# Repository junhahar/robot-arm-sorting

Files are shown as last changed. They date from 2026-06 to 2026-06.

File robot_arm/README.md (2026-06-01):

# Robot Arm Sorting

삼보모터스 실무 프로젝트. 5축 로봇암으로 볼트/너트를 인식해 자동 분류한다.

## 프로젝트 개요

전체 동작은 **마스터 궤적 재생 + Checkpoint AI 보정 하이브리드** 방식이다. 사람이 시연한 큰 동선을 그대로 재생하되, 정밀이 필요한 핵심 구간에서만 카메라·ToF 센서로 실시간 보정한다.

1. **하드웨어 구축** — 5관절축 로봇암 프레임 설계·제작, 부품 통합 및 배선 정리
2. **MPU 웨이포인트 티칭** — 사람 팔에 부착한 MPU로 동작을 녹화해 마스터 궤적(CSV) 생성
3. **볼트/너트 딥러닝 분류** — 그리퍼에 부착된 글로벌 셔터 카메라 + YOLO(Hailo 8L)로 실시간 판별
4. **실시간 위치 보정** — 작업 도중 물체 위치가 바뀌면 Checkpoint(SCAN/PRE_GRASP/GRASP/PLACE)에서 카메라·ToF·ArUco로 경로 보정

```
[티칭]  Nano#2(USB) + TCA9548A + MPU6050×3 → 노트북 → 웨이포인트 저장 → master_trajectory.csv
[자동]  RPi5가 CSV 재생 → checkpoint에서 YOLO/ToF/ArUco 보정 → 반복
```

---

## 하드웨어 구성

### 컴퓨팅 / 제어

| 장치 | 역할 | 비고 |
|---|---|---|
| 라즈베리파이5 + Hailo 8L | AI 추론(분류), 메인 제어, 궤적 재생 | CAN 마스터 |
| 노트북 | 티칭 데이터 수집, 모델 학습, 디버깅 | CAN 비참여 |
| STM32F103RB (Nucleo-F103RB) | 서보 6개 구동, 그리퍼 PWM | CAN 노드 |
| Arduino Nano #1 | VL53L0X(ToF) 읽어 CAN 송신 | CAN 노드 (MCP2515) |
| Arduino Nano #2 | MPU6050×3 읽어 노트북으로 시리얼 전송 | USB 티칭 전용, CAN 비참여 |

> E-stop은 프로젝트 방향 변경으로 제거되었다.

### 구동부

| 장치 | 수량 | 비고 |
|---|---|---|
| Feetech STS3215 | 6 | 5관절 구동 (어깨에 2개 병렬로 토크 보강) |
| MG90 메탈 기어 그리퍼 | 1 | 그리퍼 개폐 (SG90에서 교체) |
| Bus Servo Adapter | 1 | UART → STS3215 half-duplex 변환, 데이지체인 |

### 센서 / 카메라

| 장치 | 인터페이스 | 연결 |
|---|---|---|
| ArduCam USB 글로벌 셔터 | USB3 | RPi5, 그리퍼 eye-in-hand (볼트/너트 인식) |
| VL53L0X (ToF) | I2C | Nano #1 경유 → CAN |
| MPU6050 ×3 + TCA9548A | I2C | Nano #2 경유 → USB (티칭 전용) |
| 웹캠 ×2 | USB | 노트북, 영상 촬영·학습 |

### 전원

| 전원 | 출력 | 공급 대상 |
|---|---|---|
| Mean Well RSP-200-7.5 | 7.5V 정격 → 7.4V로 트림 | Bus Servo Adapter → STS3215 ×6 |
| XL4015 가변 벅 | 5V | STM32 E5V + Nano ×2 |
| RPi5 27W USB-C PD | 5V | RPi5 + Hailo 8L |

> 공통 GND 필수(서보 어댑터·컨버터·MCU 전부). 서보 전원(7.4V)을 MCU 로직 VCC에 직결 금지.

---

## CAN 통신 규약

> 앞으로 모든 CAN 통신은 아래 규약을 지켜서 구현한다. 노드 추가·펌웨어 수정 시 이 표를 기준으로 한다.

### 버스 설정

| 항목 | 값 |
|---|-----|
| 비트레이트 | **125 kbps** (전 노드 통일) |
| 샘플포인트 | **0.625** (RPi 쪽에서 명시적으로 강제) |
| ID 형식 | 표준 11-bit |
| 토폴로지 | 데이지체인, 양 끝단에만 120Ω 종단 (정상 측정값 60Ω) |

```
RPi5 ──USB── CANable Pro ═══CAN(H/L) 데이지체인═══ STM32 ─── Nano#1
            (종단 120Ω)                                    (종단 120Ω)
```

전체 CAN 노드는 **RPi5 + STM32 + Nano#1**, 총 3개다. (Nano#2는 USB 티칭 전용으로 버스에 참여하지 않는다.)

### 노드별 비트레이트 설정값

| 노드 | 설정 |
|---|---|
| RPi5 (CANable / socketcan) | `bitrate 125000`, `sample-point 0.625` 명시 |
| STM32F103RB | `Prescaler=16`, `BS1=13TQ`, `BS2=2TQ` (PCLK1 32MHz 기준 → 125k) |
| Nano #1 (MCP2515 8MHz) | `CAN_125KBPS`, `MCP_8MHZ` |

> STM32의 CAN 핀은 **PB8(RX) / PB9(TX)** 로 AFIO 리맵해서 사용한다. (PA11/PA12는 보드의 USB 회로와 충돌)

### CAN ID 할당표

| ID | 방향 | 용도 | 데이터 |
|---|---|---|---|
| `0x100` | RPi5 → STM32 | 모터 명령 | `[cmd, motor_id, pos_lo, pos_hi, 0, 0, torque, 0]` |
| `0x200` | STM32 → RPi5 | 모터 ACK | `[cmd, motor_id, status]` (status: `0x00`=OK, `0xFF`=오류) |
| `0x300` | Nano#1 → RPi5 | ToF 거리 데이터 | `[distance_lo, distance_hi]` |
| `0x37F` | RPi5 → Nano#1 | PING 요청 | (선택) |
| `0x3FF` | Nano#1 → RPi5 | PING ACK | |

**cmd 코드**

| cmd | 의미 |
|-----|---|
| `0x01` | 위치 지령 (0~4095 step) |
| `0x02` | 토크 ON/OFF |
| `0x7F` | ping |

> `0x100` / `0x200` 은 RPi↔STM32 전용이므로 절대 재사용 금지. 신규 CAN 노드를 추가할 경우 `0x400` 대역부터 할당한다.

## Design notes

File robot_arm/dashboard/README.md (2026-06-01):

# Sambo Robot Arm Dashboard

삼보모터스 로봇팔 자동 분류 시스템의 발표 및 작업자용 대시보드입니다.

## 실행 방법

1. Python 3를 설치합니다.
2. OpenAI API를 사용할 경우 PowerShell에서 개인 API 키를 등록합니다.

```powershell
setx OPENAI_API_KEY "본인이_발급받은_API_키"
```

3. 새 PowerShell 창을 열거나 PC를 재부팅합니다.
4. `대시보드_실행.bat`를 더블클릭합니다.
5. 브라우저에서 `http://127.0.0.1:8766/`에 접속합니다.

API 키는 저장소에 포함하지 않습니다. 팀원별로 개인 환경변수에 등록해야 합니다.

## 포함 기능

- 티칭 모드, 자동 운전, 수동 시험 화면
- 실제 STL 기반 3D 로봇 모델과 J1~J6 실시간 각도 연동
- J2·J3 연동 수동 제어와 HOME 복귀
- MPU 팔 동작 추정, 그리퍼 카메라, YOLO 데모 화면
- CAN, 모터, 그리퍼, ToF, 이벤트 로그 상태 표시
- OpenAI API 기반 작업자용 AI 설명 도우미

실제 장비 WebSocket 연결이 없으면 화면 상단에 `DEMO MODE`가 표시됩니다.

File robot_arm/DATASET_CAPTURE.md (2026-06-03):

# Dataset Capture Guide

데이터셋 수집 스크립트 (`dataset_capture.py`) 사용 가이드입니다.

---

## 개요

로봇팔 분류 시스템을 위한 학습 데이터 수집 스크립트입니다.  
카메라를 로봇의 실제 촬영 위치에 고정한 상태에서, 볼트/너트를 손으로 위치를 바꿔가며 촬영합니다.

---

## 수집 클래스 구성

| 클래스 | 장수 | 설명 |
|---|---|---|
| `nut` | 200 | 너트 |
| `bolt_lie_000_015` | 50 | 누운 볼트 0°~15° |
| `bolt_lie_015_030` | 50 | 누운 볼트 15°~30° |
| `bolt_lie_030_045` | 50 | 누운 볼트 30°~45° |
| `bolt_lie_045_060` | 50 | 누운 볼트 45°~60° |
| `bolt_lie_060_075` | 50 | 누운 볼트 60°~75° |
| `bolt_lie_075_090` | 50 | 누운 볼트 75°~90° |
| `bolt_lie_090_105` | 50 | 누운 볼트 90°~105° |
| `bolt_lie_105_120` | 50 | 누운 볼트 105°~120° |
| `bolt_lie_120_135` | 50 | 누운 볼트 120°~135° |
| `bolt_lie_135_150` | 50 | 누운 볼트 135°~150° |
| `bolt_lie_150_165` | 50 | 누운 볼트 150°~165° |
| `bolt_lie_165_180` | 50 | 누운 볼트 165°~180° |
| **합계** | **800** | |

> bolt_lie 각도는 그리퍼 회전 보정에 사용됩니다.

---

## 설치

```bash
pip install opencv-python
```

---

## 실행

```bash
python dataset_capture.py
```

nut → bolt_lie 12구간 순서로 자동 진행됩니다.

---

## 조작 방법

| 키 | 동작 |
|----|---|
| `Space` | 촬영 시작 / 일시정지 |
| `Q` | 현재 클래스 종료 후 다음 클래스로 이동 |

- 초록 테두리: 일시정지 상태
- 주황 테두리: 촬영 중 상태

---

## 저장 구조

```
dataset/
└── raw/
    ├── nut/
    │   ├── nut_0000.jpg
    │   ├── nut_0001.jpg
    │   └── ...
    ├── bolt_lie_000_015/
    │   ├── bolt_lie_000_015_0000.jpg
    │   └── ...
    └── bolt_lie_165_180/
        └── ...
```

---

## 촬영 주의사항

### 카메라 위치
- **반드시 로봇의 실제 작업 위치에 카메라를 고정**
- 촬영 도중 카메라 위치 변경 금지

### 데이터 다양성 확보 (중요)
- 물체를 화면 내 다양한 위치에 놓기 (왼쪽, 중앙, 오른쪽, 위, 아래)
- 각 구간 내에서도 각도를 조금씩 다르게
- 조명 변화도 일부 포함 권장

### 볼트 각도 측정
- 볼트의 긴 축을 기준으로 수평(0°)부터 측정
- 각도기 또는 촬영 보조 도구 사용 권장

### 저장 간격
- 기본 `interval=1.0` (1초마다 자동 저장)
- 손으로 물체 위치 바꾸기에 충분한 시간

---

## 재촬영

특정 클래스만 재촬영할 경우, `dataset/raw/{class_name}/` 폴더를 삭제 후 재실행하면 해당 클래스부터 다시 시작합니다.  
기존 이미지가 남아있으면 이어서 수집합니다.

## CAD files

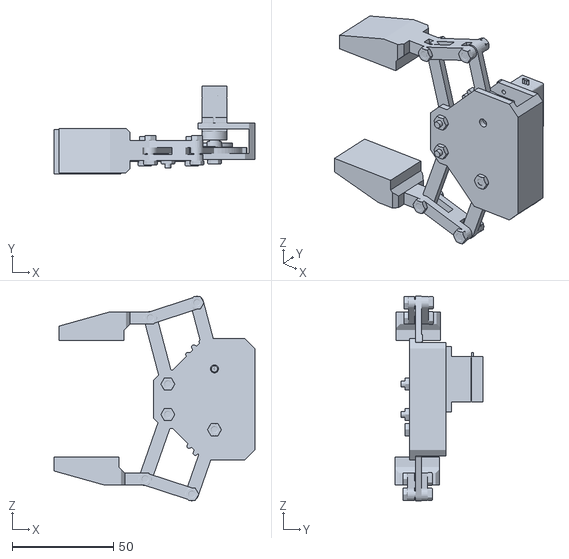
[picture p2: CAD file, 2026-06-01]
robot_arm/dashboard/models/gripper/Assembly 2.0 upload v1.stl
99.2 x 43.3 x 101.0

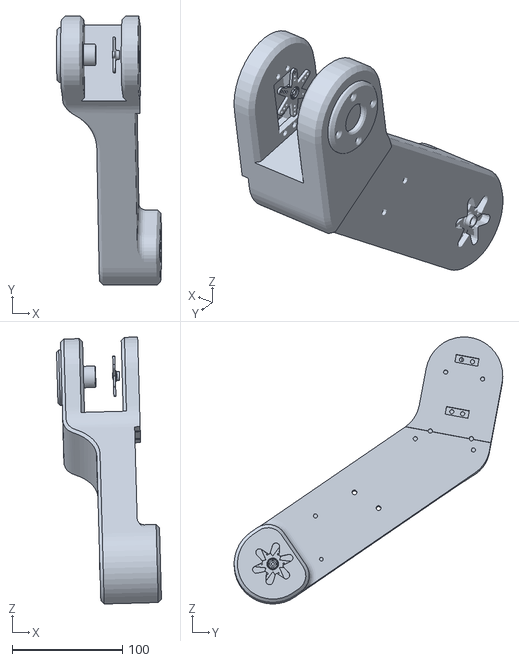
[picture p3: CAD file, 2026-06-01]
robot_arm/dashboard/models/arm1/arm1.stl
95.1 x 243.3 x 241.9

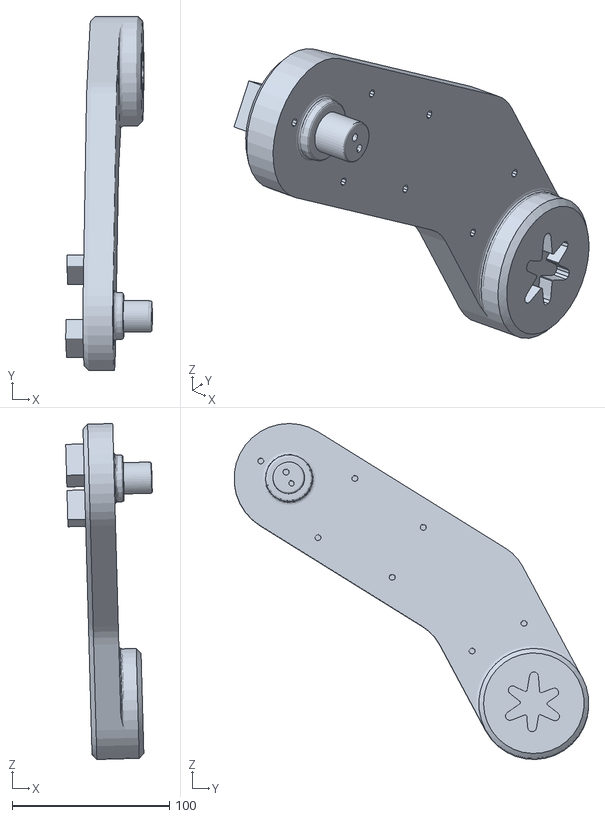
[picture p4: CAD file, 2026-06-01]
robot_arm/dashboard/models/arm2/arm2.stl
55.2 x 225.6 x 213.8

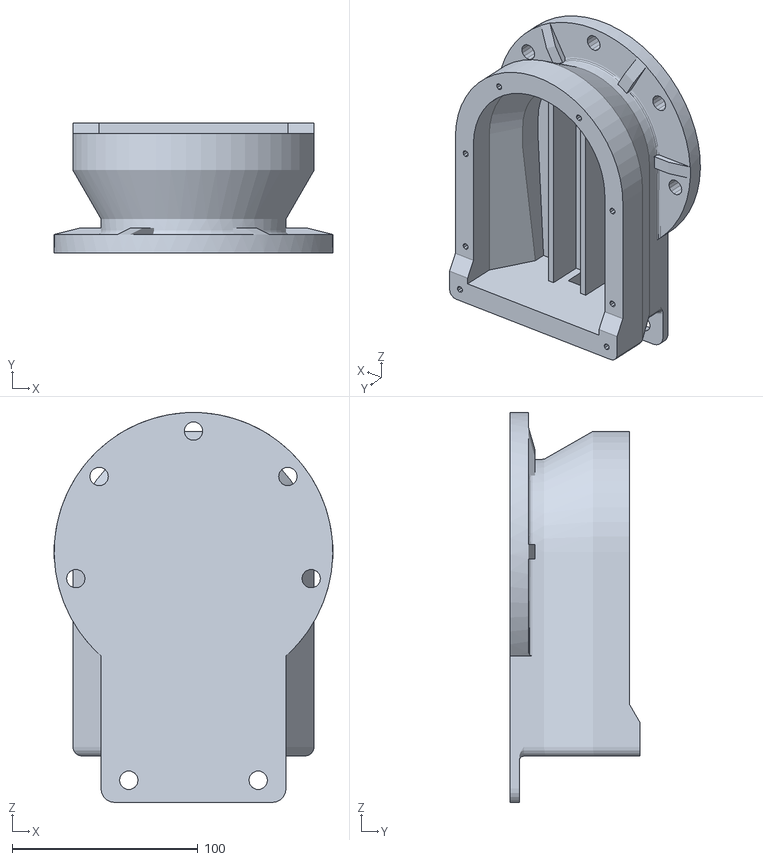
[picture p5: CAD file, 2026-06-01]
robot_arm/dashboard/models/base/base.stl
150.0 x 70.0 x 210.0

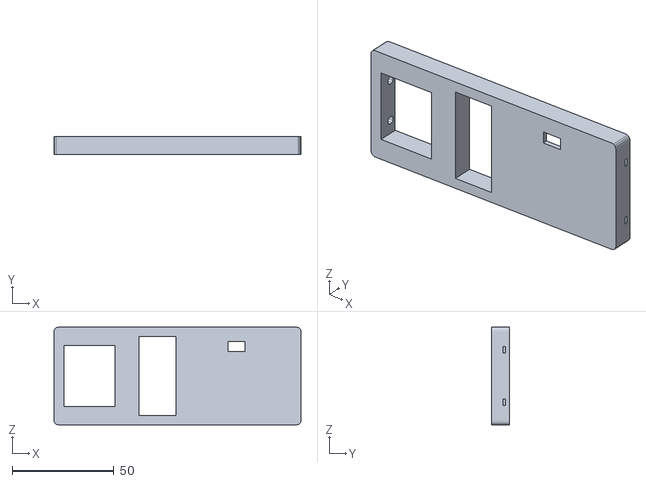
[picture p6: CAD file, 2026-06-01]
robot_arm/dashboard/models/camera_braket/last_camerabraket.stl
121.5 x 9.00 x 48.0

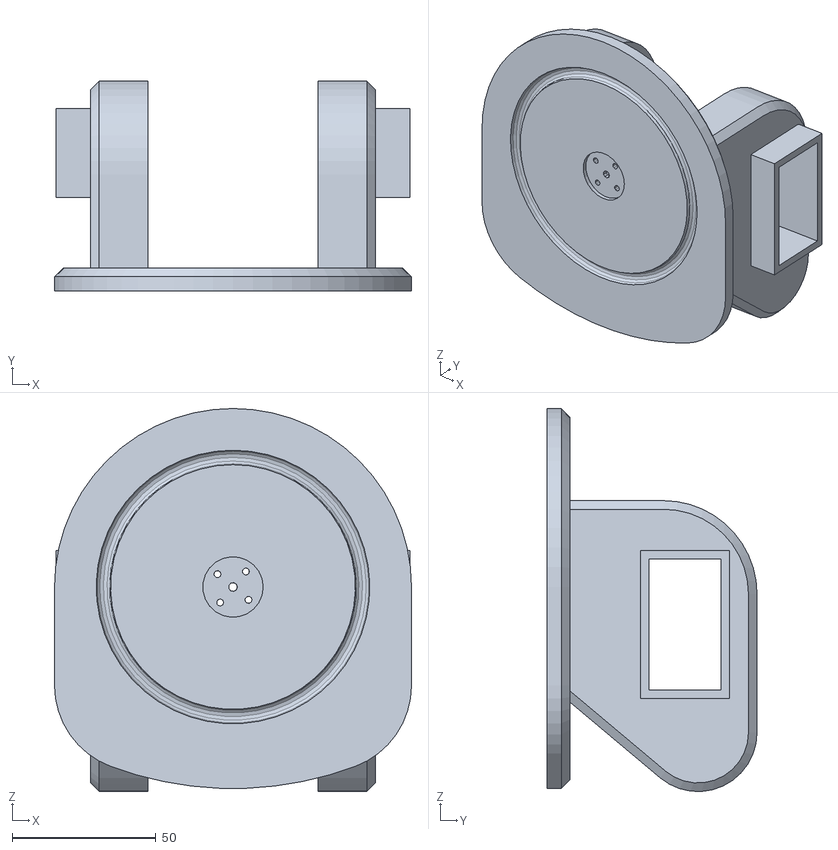
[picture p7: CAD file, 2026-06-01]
robot_arm/dashboard/models/shorder/shorder.stl
124.0 x 73.0 x 133.0

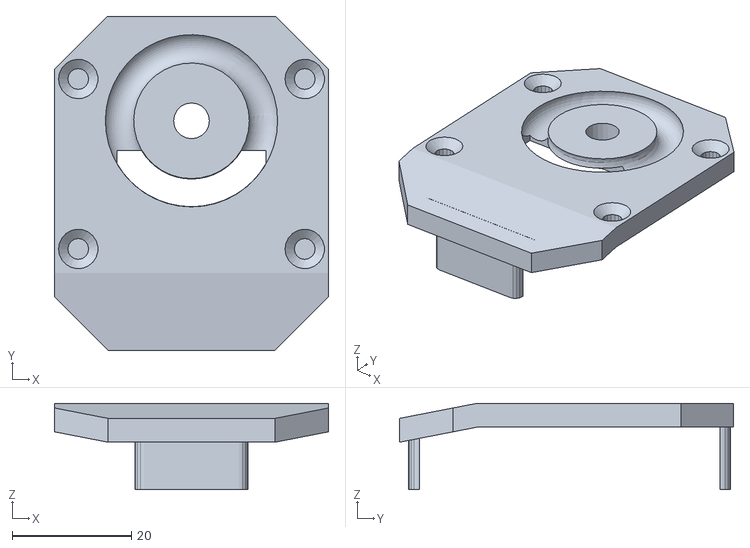
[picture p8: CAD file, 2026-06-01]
robot_arm/dashboard/models/wrist/write_plate.stl
46.0 x 56.0 x 14.5

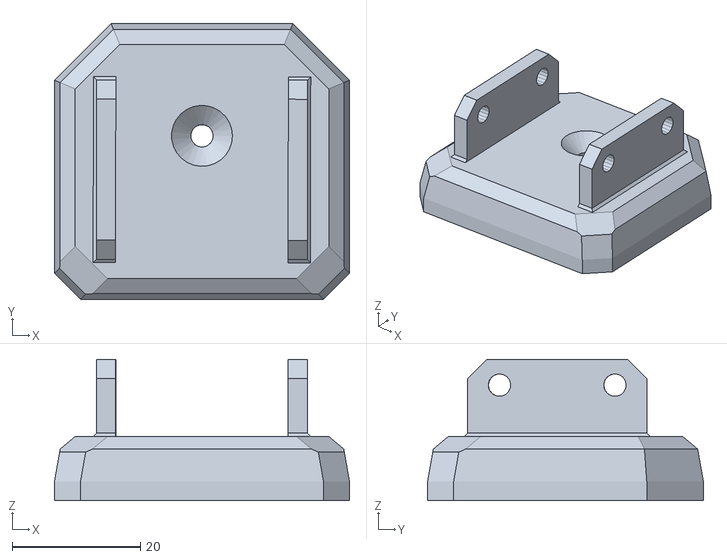
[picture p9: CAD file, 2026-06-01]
robot_arm/dashboard/models/wrist_roll/Draaiplaat gripper.stl
46.0 x 43.0 x 22.0

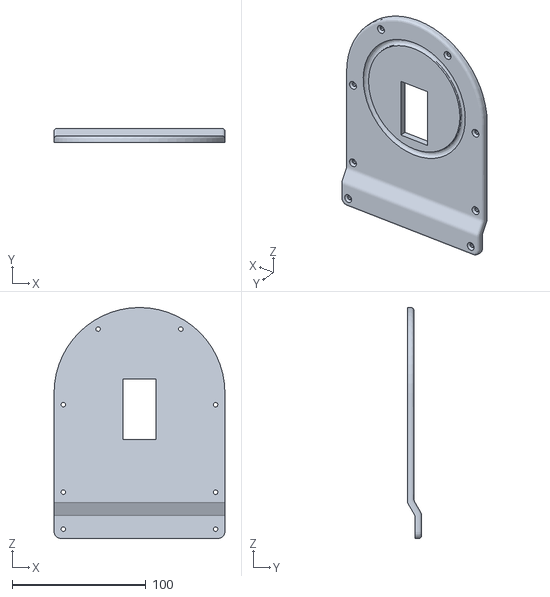
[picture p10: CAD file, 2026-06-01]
robot_arm/dashboard/models/base/basecover1.stl
128.0 x 10.7 x 173.0

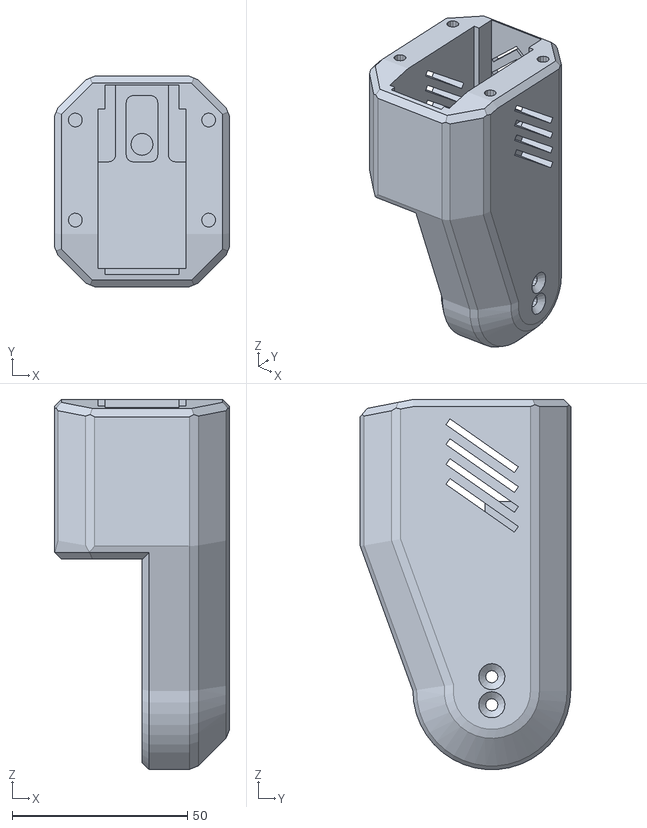
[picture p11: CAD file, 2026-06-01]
robot_arm/dashboard/models/wrist/new_write_house.stl
50.0 x 60.0 x 105.4

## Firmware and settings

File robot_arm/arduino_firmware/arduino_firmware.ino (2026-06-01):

/*
 * Arduino Uno 펌웨어 — CAN ↔ STS3215 브릿지
 *
 * 통신 경로:
 *   RPi5 → USB → CANable Pro → CAN → MCP2515 → SPI → Arduino Uno
 *   Arduino Uno → Hardware UART (D0/D1) → Bus Servo Driver → STS3215 x6
 *
 * 배선:
 *   MCP2515  → SPI (10=CS, 11=MOSI, 12=MISO, 13=SCK)
 *   Bus Servo Driver → Hardware Serial (D0=RX, D1=TX)
 *   SG90     → PWM pin 9
 *   VL53L0X  → I2C (A4=SDA, A5=SCL)
 *   E-STOP   → pin 2 (INPUT_PULLUP)
 *
 * 주의:
 *   D0/D1이 USB와 공유 → 펌웨어 업로드 시 Bus Servo Driver 분리
 *
 * 필요 라이브러리:
 *   - mcp_can (Seeed Studio 또는 coryjfowler)
 *   - SCServo (Feetech)
 *   - Servo (Arduino 기본)
 *   - VL53L0X (Pololu) — ToF 사용 시
 */

#include <SPI.h>
#include <mcp_can.h>
#include <SCServo.h>
#include <Servo.h>
#include <Wire.h>

// ─── Pin 정의 ───────────────────────────────────────────────
#define CAN_CS_PIN   10
#define GRIPPER_PIN  9
#define ESTOP_PIN    2
#define FSR_PIN      A0

// ─── 설정 ───────────────────────────────────────────────────
#define SERVO_BAUD   1000000  // STS3215 기본 1Mbps (Hardware Serial)
#define CAN_SPEED    CAN_500KBPS
#define MCP_CLOCK    MCP_8MHZ

// ─── CAN Message ID (config.py와 동일) ──────────────────────
#define CAN_ID_SERVO_MOVE  0x10
#define CAN_ID_SERVO_READ  0x11
#define CAN_ID_GRIPPER     0x12
#define CAN_ID_TOF_READ    0x13
#define CAN_ID_FSR_READ    0x14
#define CAN_ID_ESTOP       0xFF

#define CAN_ID_SERVO_POS   0x20
#define CAN_ID_TOF_DIST    0x21
#define CAN_ID_FSR_VAL     0x22

// ─── 객체 생성 ──────────────────────────────────────────────
MCP_CAN CAN(CAN_CS_PIN);
SMS_STS sms_sts;
Servo gripper;

bool estop_active = false;

// ─── ToF (VL53L0X) ─────────────────────────────────────────
#define TOF_ADDR  0x29
bool tofReady = false;

uint16_t readToF() {
    if (!tofReady) return 9999;

    Wire.beginTransmission(TOF_ADDR);
    Wire.write(0x00);
    Wire.write(0x01);
    Wire.endTransmission();

    delay(30);

    Wire.beginTransmission(TOF_ADDR);
    Wire.write(0x1E);
    Wire.endTransmission();
    Wire.requestFrom(TOF_ADDR, (uint8_t)2);

    if (Wire.available() >= 2) {
        uint16_t dist = Wire.read() << 8;
        dist |= Wire.read();
        return dist;
    }
    return 9999;
}

// ─── CAN 응답 ───────────────────────────────────────────────
void canSend(uint32_t id, uint8_t *data, uint8_t len) {
    CAN.sendMsgBuf(id, 0, len, data);
}

// ─── 명령 처리 ──────────────────────────────────────────────

void handleServoMove(uint8_t *buf) {
    uint8_t servoId = buf[0];
    uint16_t pos = ((uint16_t)buf[1] << 8) | buf[2];
    sms_sts.WritePosEx(servoId, (int)pos, 0, 0);
}

void handleServoRead(uint8_t *buf) {
    uint8_t servoId = buf[0];
    int pos = sms_sts.ReadPos(servoId);
    if (pos < 0) pos = 0;

    uint8_t resp[3];
    resp[0] = servoId;
    resp[1] = (uint8_t)(pos >> 8);
    resp[2] = (uint8_t)(pos & 0xFF);
    canSend(CAN_ID_SERVO_POS, resp, 3);
}

void handleGripper(uint8_t *buf) {
    gripper.write(buf[0]);
}

void handleToFRead() {
    uint16_t dist = readToF();
    uint8_t resp[2];
    resp[0] = (uint8_t)(dist >> 8);
    resp[1] = (uint8_t)(dist & 0xFF);
    canSend(CAN_ID_TOF_DIST, resp, 2);
}

void handleFSRRead() {
    uint16_t val = analogRead(FSR_PIN);
    uint8_t resp[2];
    resp[0] = (uint8_t)(val >> 8);
    resp[1] = (uint8_t)(val & 0xFF);
    canSend(CAN_ID_FSR_VAL, resp, 2);
}

void handleEStop() {
    estop_active = true;
    for (int id = 1; id <= 5; id++) {
        sms_sts.EnableTorque(id, 0);
    }
    gripper.write(90);
}

// ─── Setup ──────────────────────────────────────────────────

void setup() {
    // E-STOP 버튼
    pinMode(ESTOP_PIN, INPUT_PULLUP);

    // STS3215 — Hardware Serial (D0/D1) via Bus Servo Driver
    Serial.begin(SERVO_BAUD);
    sms_sts.pSerial = &Serial;

    // 그리퍼
    gripper.attach(GRIPPER_PIN);
    gripper.write(90);

    // CAN 초기화
    while (CAN.begin(MCP_ANY, CAN_SPEED, MCP_CLOCK) != CAN_OK) {
        delay(100);
    }
    CAN.setMode(MCP_NORMAL);

    // ToF 초기화
    Wire.begin();
    Wire.beginTransmission(TOF_ADDR);
    tofReady = (Wire.endTransmission() == 0);
}

// ─── Main Loop ──────────────────────────────────────────────

void loop() {
    // 물리 E-STOP 체크
    if (digitalRead(ESTOP_PIN) == LOW && !estop_active) {
        handleEStop();
        uint8_t data[1] = {0xFF};
        canSend(CAN_ID_SERVO_POS, data, 1);
    }

    if (estop_active) {
        delay(100);
        return;
    }

    // CAN 메시지 수신
    if (CAN.checkReceive() != CAN_MSGAVAIL) return;

    long unsigned int canId;
    unsigned char len = 0;
    unsigned char buf[8];

    if (CAN.readMsgBuf(&canId, &len, buf) != CAN_OK) return;

    switch (canId) {
        case CAN_ID_SERVO_MOVE:
            if (len >= 3) handleServoMove(buf);
            break;
        case CAN_ID_SERVO_READ:
            if (len >= 1) handleServoRead(buf);
            break;
        case CAN_ID_GRIPPER:
            if (len >= 1) handleGripper(buf);
            break;
        case CAN_ID_TOF_READ:
            handleToFRead();
            break;
        case CAN_ID_FSR_READ:
            handleFSRRead();
            break;
        case CAN_ID_ESTOP:
            handleEStop();
            break;
    }
}

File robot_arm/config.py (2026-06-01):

# ─── Named Poses (degrees) ─────────────────────────────────
HOME = {"J1": 90.0, "J2": 120.0, "J3": 150.0, "J4": 80.0, "J5": 90.0}
CARRY = {"J1": 90.0, "J2": 100.0, "J3": 120.0, "J4": 90.0, "J5": 90.0}

# ─── CAN Bus (CANable Pro ↔ MCP2515) ───────────────────────
CAN_CHANNEL = "can0"
CAN_BUSTYPE = "socketcan"
CAN_BITRATE = 125000

# CAN Message IDs — RPi5 → Arduino Uno
CAN_ID_SERVO_MOVE = 0x10   # [servo_id:u8, position:u16]
CAN_ID_SERVO_READ = 0x11   # [servo_id:u8]
CAN_ID_GRIPPER    = 0x12   # [angle:u8]
CAN_ID_TOF_READ   = 0x13   # []
CAN_ID_ESTOP      = 0xFF   # []

# CAN Message IDs — STM32 → RPi5
CAN_ID_SERVO_POS  = 0x20   # [servo_id:u8, position:u16]
CAN_ID_TOF_DIST   = 0x21   # [distance:u16]

# ─── STS3215 Servo ──────────────────────────────────────────
SERVO_CENTER = 2048
SERVO_STEPS_PER_DEG = 4096.0 / 360.0  # ~11.378

JOINTS = {
    "J1": {"servo_id": 1,      "min": 0,   "max": 270, "home": 90.0,  "dir": 1},
    "J2": {"servo_id": [2, 3], "min": 0,   "max": 270, "home": 120.0, "dir": [1, -1]},
    "J3": {"servo_id": 4,      "min": 0,   "max": 270, "home": 150.0, "dir": 1},
    "J4": {"servo_id": 5,      "min": -90, "max": 270, "home": 80.0,  "dir": 1},
    "J5": {"servo_id": 6,      "min": 0,   "max": 270, "home": 90.0,  "dir": 1},
}

# ─── Gripper (SG90) ─────────────────────────────────────────
GRIPPER_OPEN = 90
GRIPPER_CLOSE = 30
GRIP_CLOSE_WAIT = 0.5  # seconds

# ─── FSR (압력 센서) ────────────────────────────────────────
FSR_THRESHOLD = 100  # 아날로그 값, 조립 후 실측

# ─── IK ─────────────────────────────────────────────────────
IK_L2 = 245.0  # upper arm (mm)
IK_L3 = 212.0  # forearm (mm)

# IK joint angle mapping (internal rad <-> servo deg)
IK_J2_OFFSET = 75.0
IK_J2_RANGE_DEG = 150.0
IK_J3_OFFSET = 90.0
IK_J3_RANGE_DEG = 135.0
IK_J4_OFFSET = 90.0
IK_J4_RANGE_DEG = 120.0
GRIP_OFFSET_RAD = -1.5708  # -pi/2, 수직 파지. 조립 후 실측

# ─── Work Surface ───────────────────────────────────────────
WORK_SURFACE_Z = -150.0  # mm below base, 조립 후 실측
PRE_GRASP_Z = WORK_SURFACE_Z + 40.0
GRASP_DIST = 30       # mm — ToF 이 거리 이하면 그리퍼 닫기
PLACE_DIST = 15       # mm — bin 내부 놓기 거리
DESCEND_STEP_MM = 5.0
LIFT_HEIGHT = 40.0    # mm — 파지 후 들어올리기
MAX_PLACE_DEPTH = 120.0  # mm — bin 최대 하강 깊이
MAX_DESCEND_DEPTH = 200.0  # mm — 작업대 최대 하강

# ─── ArUco ──────────────────────────────────────────────────
ARUCO_DICT = "DICT_4X4_50"
ENV_ARUCO_ID = 0       # 환경 보정용 마커 ID
BIN_ARUCO = {
    "bolt":   {"id": 1, "offset_x": 0.0, "offset_y": 50.0},
    "nut":    {"id": 2, "offset_x": 0.0, "offset_y": 50.0},
    "washer": {"id": 3, "offset_x": 0.0, "offset_y": 50.0},
}

# ─── Camera (ArduCam OV9782, eye-in-hand) ───────────────────
CAMERA_ID = 0
CALIB_FILE = "camera_calib.npz"
# 핀홀 카메라 파라미터 — 체커보드 캘리브레이션 후 실측값으로 교체
CAM_FX = 600.0
CAM_FY = 600.0
CAM_CX = 320.0
CAM_CY = 240.0
# 카메라 마운트 오프셋 (그리퍼 기준, mm) — 오른쪽+안쪽 틸트
CAM_OFFSET_X = 30.0   # 그리퍼 기준 오른쪽 (mm), 조립 후 실측
CAM_OFFSET_Y = 0.0    # 그리퍼 기준 전방 (mm), 조립 후 실측

# ─── Visual Servoing ────────────────────────────────────────
GRIPPER_PX = 350      # 그리퍼 중심에 대응하는 픽셀 X, 조립 후 실측
GRIPPER_PY = 280      # 그리퍼 중심에 대응하는 픽셀 Y, 조립 후 실측
VS_GAIN = 0.3         # Visual Servoing 게인 (낮게 시작)
VS_TOLERANCE = 15     # 수렴 판정 (pixels)
VS_MAX_ITER = 10      # 최대 반복 횟수

# ─── YOLO ────────────────────────────────────────────────────
YOLO_CONF = 0.7
STABLE_FRAMES = 3     # 연속 검출 프레임 수
CLASS_NAMES = {0: "bolt", 1: "nut", 2: "washer"}

# ─── Bins (대략적 J1, 티칭 궤적) ────────────────────────────
BINS = {
    "bolt":   {"j1": 45.0,  "traj": "bolt_place.csv"},
    "nut":    {"j1": 135.0, "traj": "nut_place.csv"},
    "washer": {"j1": 180.0, "traj": "washer_place.csv"},
}

# ─── Trajectories ───────────────────────────────────────────
TRAJECTORY_DIR = "trajectories"
SCAN_TRAJ = "scan_path.csv"

# ─── S-curve Motion ─────────────────────────────────────────
MOVE_DURATION = 1.0
MOVE_DURATION_FAST = 0.3
CONTROL_PERIOD_MS = 20

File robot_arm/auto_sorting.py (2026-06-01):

"""
마스터 궤적 재생 + Checkpoint AI 보정

웨이포인트 CSV를 순서대로 재생하며, checkpoint 지점에서
카메라/ToF 기반 실시간 보정을 수행한다.

Checkpoint:
  SCAN      — YOLO 검출 → 물체 오프셋 계산
  PRE_GRASP — Visual Servoing → 미세 정렬
  GRASP     — ToF 하강 → 그리퍼 닫기
  PLACE     — ArUco → bin 위치 보정 → 그리퍼 열기

실행:
  python auto_sorting.py --trajectory master_cycle.csv
  python auto_sorting.py --trajectory master_cycle.csv --dry-run
"""
import os
import csv
import time
import math
import argparse

from config import (
    HOME, CARRY,
    GRASP_DIST, PLACE_DIST, DESCEND_STEP_MM, LIFT_HEIGHT,
    MAX_PLACE_DEPTH, MAX_DESCEND_DEPTH,
    GRIP_CLOSE_WAIT,
    ARUCO_DICT, BIN_ARUCO,
    CAMERA_ID, CAM_FX, CAM_FY,
    CAM_OFFSET_X, CAM_OFFSET_Y,
    GRIPPER_PX, GRIPPER_PY, VS_GAIN, VS_TOLERANCE, VS_MAX_ITER,
    YOLO_CONF, STABLE_FRAMES,
    TRAJECTORY_DIR,
    MOVE_DURATION, MOVE_DURATION_FAST,
)
from servo_driver import ServoDriver
import ik
import s_curve


# ═══════════════════════════════════════════════════════════════
# 설정
# ═══════════════════════════════════════════════════════════════

CORRECTION_LIMIT = 15.0  # 보정 최대 범위 (degrees)
DEFAULT_TRAJECTORY = "master_cycle.csv"


# ═══════════════════════════════════════════════════════════════
# Trajectory I/O
# ═══════════════════════════════════════════════════════════════

def load_trajectory(name):
    path = os.path.join(TRAJECTORY_DIR, name)
    if not os.path.exists(path):
        return None
    with open(path, "r") as f:
        rows = []
        for row in csv.DictReader(f):
            parsed = {}
            for k, v in row.items():
                if k in ("gripper", "checkpoint"):
                    parsed[k] = v.strip()
                elif k == "seq":
                    parsed[k] = int(v)
                else:
                    parsed[k] = float(v)
            rows.append(parsed)
        return rows


def traj_to_pose(row):
    return {j: row[j] for j in ["J1", "J2", "J3", "J4", "J5"] if j in row}


# ═══════════════════════════════════════════════════════════════
# YOLO Detector
# ═══════════════════════════════════════════════════════════════

class YoloDetector:

    def __init__(self, model_path=None, dry_run=False):
        self.dry_run = dry_run
        self.model = None
        if not dry_run and model_path:
            self._load_model(model_path)

    def _load_model(self, path):
        try:
            from hailo_platform import HEF, VDevice
            self.hef = HEF(path)
            self.device = VDevice()
            self.model = self.device.configure(self.hef)
            print(f"[YOLO] Hailo model loaded: {path}")
        except ImportError:
            print("[YOLO] hailo_platform not installed — dry-run")
            self.dry_run = True
        except Exception as e:
            print(f"[YOLO] Model load failed: {e} — dry-run")
            self.dry_run = True

    def detect(self, frame):
        if self.dry_run:
            return []
        return []


# ═══════════════════════════════════════════════════════════════
# Camera
# ═══════════════════════════════════════════════════════════════

class Camera:

    def __init__(self, camera_id=CAMERA_ID, dry_run=False):
        self.dry_run = dry_run
        self.cap = None
        self.aruco_detector = None

        if not dry_run:
            import cv2
            import cv2.aruco as aruco
            self.cap = cv2.VideoCapture(camera_id)
            if not self.cap.isOpened():
                print(f"[CAM] Camera {camera_id} failed — dry-run")
                self.dry_run = True
            else:
                dictionary = aruco.getPredefinedDictionary(
                    getattr(aruco, ARUCO_DICT)
                )
                self.aruco_detector = aruco.ArucoDetector(
                    dictionary, aruco.DetectorParameters()
                )

    def read(self):
        if self.dry_run:
            return None
        import cv2
        ret, frame = self.cap.read()
        return frame if ret else None

    def pixel_to_mm(self, px, py, height_mm):
        from config import CAM_CX, CAM_CY
        x_mm = (px - CAM_CX) * height_mm / CAM_FX
        y_mm = (py - CAM_CY) * height_mm / CAM_FY
        return x_mm, y_mm

    def detect_aruco(self, frame):
        if self.aruco_detector is None:
            return {}
        import cv2
        gray = cv2.cvtColor(frame, cv2.COLOR_BGR2GRAY)
        corners, ids, _ = self.aruco_detector.detectMarkers(gray)
        if ids is None:
            return {}
        result = {}
        for i, marker_id in enumerate(ids.flatten()):
            center = corners[i][0].mean(axis=0)
            result[int(marker_id)] = (float(center[0]), float(center[1]))
        return result

    def close(self):
        if self.cap:
            self.cap.release()


# ═══════════════════════════════════════════════════════════════
# 보정 유틸
# ═══════════════════════════════════════════════════════════════

def clamp_correction(base, corrected, limit=CORRECTION_LIMIT):
    delta = corrected - base
    if abs(delta) > limit:
        return base + limit * (1.0 if delta > 0 else -1.0)
    return corrected


def apply_offset(pose, offset_j1):
    adjusted = dict(pose)
    adjusted["J1"] = clamp_correction(pose["J1"], pose["J1"] + offset_j1)
    return adjusted


# ═══════════════════════════════════════════════════════════════
# Trajectory Player
# ═══════════════════════════════════════════════════════════════
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

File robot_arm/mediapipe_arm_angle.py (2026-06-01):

import cv2
import mediapipe as mp
import numpy as np
import math
import time
import os
import csv
import json
import threading
from config import CARRY

mp_pose = mp.solutions.pose
mp_draw = mp.solutions.drawing_utils

FRONT_CAM = 1
SIDE_CAM = 2
SMOOTH_WINDOW = 3
MAX_DELTA = 5.0
DEAD_ZONE = 2.0
MIN_VISIBILITY = 0.7
SAFE_RANGE = 40.0


class LowPassFilter:
    def __init__(self, alpha=0.3):
        self.alpha = alpha
        self.last = None

    def filter(self, val):
        if self.last is None:
            self.last = val
            return val
        self.last += self.alpha * (val - self.last)
        return self.last


class LandmarkSmoother:
    def __init__(self, alpha=0.3):
        self.alpha = alpha
        self.filters = {}

    def smooth(self, cam_id, landmarks):
        if cam_id not in self.filters:
            self.filters[cam_id] = {i: (LowPassFilter(self.alpha), LowPassFilter(self.alpha), LowPassFilter(self.alpha))
                                     for i in range(33)}
        for i, lm in enumerate(landmarks):
            fx, fy, fz = self.filters[cam_id][i]
            lm.x = fx.filter(lm.x)
            lm.y = fy.filter(lm.y)
            lm.z = fz.filter(lm.z)
        return landmarks


class Smoother:
    def __init__(self, window=SMOOTH_WINDOW):
        self.window = window
        self.buffers = {}

    def smooth(self, key, value):
        if key not in self.buffers:
            self.buffers[key] = []
        buf = self.buffers[key]
        buf.append(value)
        if len(buf) > self.window:
            buf.pop(0)
        return sum(buf) / len(buf)


smoother = Smoother()
lm_smoother = LandmarkSmoother(alpha=0.3)

ws_joints = {"J1": 90.0, "J2": 120.0, "J3": 150.0, "J4": 80.0, "J5": 90.0, "gripper": "open"}

try:
    import asyncio
    import websockets

    _ws_clients = set()

    async def _ws_handler(websocket, path=None):
        _ws_clients.add(websocket)
        try:
            async for _ in websocket:
                pass
        except Exception:
            pass
        finally:
            _ws_clients.discard(websocket)

    async def _ws_loop():
        server = await websockets.serve(_ws_handler, "localhost", 8765)
        while True:
            if _ws_clients:
                msg = json.dumps(ws_joints)
                for c in list(_ws_clients):
                    try:
                        await c.send(msg)
                    except Exception:
                        _ws_clients.discard(c)
            await asyncio.sleep(0.033)

    def _start_ws():
        loop = asyncio.new_event_loop()
        asyncio.set_event_loop(loop)
        loop.run_until_complete(_ws_loop())

    threading.Thread(target=_start_ws, daemon=True).start()
    print("[INFO] WebSocket: ws://localhost:8765")
except ImportError:
    print("[WARN] websockets 미설치 - pip install websockets")
except Exception as e:
    print(f"[WARN] WebSocket 실패: {e}")


IK_L2 = 245.0
IK_L3 = 212.0
IK_R_DEF = 322.0
IK_Z_DEF = 285.0
IK_GRIP_A = 0.175


def _ik_2link(target_r, target_z):
    target_r = max(target_r, 30.0)
    d = math.sqrt(target_r ** 2 + target_z ** 2)
    d_max = IK_L2 + IK_L3 - 10
    d_min = abs(IK_L2 - IK_L3) + 10
    d_clamped = float(np.clip(d, d_min, d_max))
    if d > 1e-6 and d_clamped != d:
        s = d_clamped / d
        target_r *= s
        target_z *= s
        d = d_clamped

    gamma = math.atan2(-target_z, target_r)
    cos_e = float(np.clip((IK_L2 ** 2 + IK_L3 ** 2 - d ** 2) / (2 * IK_L2 * IK_L3), -1, 1))
    elbow_int = math.acos(cos_e)
    cos_a = float(np.clip((IK_L2 ** 2 + d ** 2 - IK_L3 ** 2) / (2 * IK_L2 * d), -1, 1))
    alpha = math.acos(cos_a)

    a1 = gamma - alpha
    rel3 = math.pi - elbow_int
    a2 = a1 + rel3
    rel4 = IK_GRIP_A - a2

    j2 = float(np.clip(75.0 + (a1 + math.pi / 2) * 150.0 / math.pi, 75, 150))
    j3 = float(np.clip(90.0 + rel3 * 135.0 / math.pi, 0, 170))
    j4 = float(np.clip(90.0 + rel4 * 120.0 / math.pi, 30, 150))
    return j2, j3, j4


def solve_ik(nx, dny, delbow):
    """기하학 IK.
    nx: 좌우 delta (-1~1)
    dny: 상하 delta (양수=손 내림)
    delbow: 팔꿈치 각도 delta (도)
    """
    j1 = float(np.clip(90 + nx * 80, 0, 180))
    target_r = IK_R_DEF + delbow * 3.0
    target_z = IK_Z_DEF - dny * 350
    j2, j3, j4 = _ik_2link(target_r, target_z)
    j5 = 90.0
    return j1, j2, j3, j4, j5


LINK_LENGTHS = [24, 148, 128]  # 실측 40.5:245:212mm 비례 (×0.6 스케일)
VIEW_AZIM = math.radians(35)
VIEW_ELEV = math.radians(25)


def project_3d(pt, center=(250, 380)):
    x, y, z = pt
    ca, sa = math.cos(VIEW_AZIM), math.sin(VIEW_AZIM)
    rx = x * ca + z * sa
    rz = -x * sa + z * ca
    ce, se = math.cos(VIEW_ELEV), math.sin(VIEW_ELEV)
    ry = y * ce - rz * se
    return (int(center[0] + rx), int(center[1] - ry))
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

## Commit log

2026-06-01 feat: 로봇팔 전체 소스 + 디지털 트윈 대시보드
    - 서보 드라이버 (STS3215, CAN 통신)
    - MPU6050 웨이포인트 티칭 도구
    - 3D 시뮬레이션 대시보드 (Three.js)
    - Running 모드 디지털 트윈 (실시간 서보 피드백)
    - WebSocket 중계 서버 + J1 테스트 스크립트
    - Arduino/STM32 펌웨어, IK, S-curve, 자동분류
    [traj_1779772013.csv, traj_1779772031.csv, traj_1779772194.csv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]
2026-06-01 docs: 프로젝트 주제·하드웨어 구성·CAN 통신 규약으로 README 갱신
2026-06-01 feat: add operator dashboard with STL robot simulation
    [Assembly 2.0 upload v1.stl, Draaiplaat gripper.stl, arm1.stl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]
2026-06-03 fix: remap wrist joints in dashboard simulation
2026-06-03 fix: allow 360 manual range for all joints
2026-06-03 feat: add digital twin servo mapping
2026-06-03 feat: add raspberry pi dashboard websocket bridge
2026-06-03 feat(camera): add dataset capture script and guide
    - dataset_capture.py: auto capture, Space/Q controls, 1s interval
    - DATASET_CAPTURE.md: usage guide, class structure, capture tips
    - Classes: nut(200) + bolt_lie x12 angles(50 each) = 800 total
